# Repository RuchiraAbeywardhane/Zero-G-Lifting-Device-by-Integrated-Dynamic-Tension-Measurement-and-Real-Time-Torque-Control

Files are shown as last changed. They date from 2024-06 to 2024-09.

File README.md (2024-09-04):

# ZeroG Lifting Device by Integrated Dynamic Tension Measurement and Real Time Torque Control
Zero G Weight Support Device assists patients struggling with walking by providing weight support to practice and improve mobility. It combines advanced mechanical engineering and electronic control systems, offering a safe and effective rehabilitation tool. This device helps patients build strength and confidence in their walking abilities.

## Project Overview

The zero gravity lifting device is designed to counteract gravity, allowing objects to be lifted and manipulated with minimal effort. It uses a load cell to measure tension, processes this information through a PID controller, and adjusts a stepper motor's velocity to achieve the desired effect.

## Components

1. ATmega328P microcontroller
2. HX711 load cell amplifier
3. Stepper motor
4. Custom PCB

## Key Features

- Real-time weight measurement using HX711 load cell amplifier
- PID control algorithm for smooth and accurate motor control
- Stepper motor control for precise movements
- Millisecond time tracking for accurate derivative calculations

## Setup and Compilation

The project is developed using WinAVR for the ATmega328P microcontroller.

## Main Program Flow

1. Initialize USART, millisecond timer, and interrupts
2. Initialize and calibrate the HX711 load cell amplifier
3. Set up the PID controller
4. Enter the main loop:
   - Read weight from the load cell
   - Calculate weight change rate (derivative)
   - Process through PID controller
   - Control stepper motor based on PID output

## Notes for Developers

- The PID constants (P_FACTOR, I_FACTOR, D_FACTOR) may need tuning for optimal performance
- The DELAY_MICROSECONDS constant in the stepper motor control can be adjusted to change motor speed
- The HX711 calibration process is crucial for accurate weight measurements

## Code Details

### HX711 Library (`HX711.h`)

This custom library provides functions for interfacing with the HX711 load cell amplifier. Key functions include:

- `HX711_init()`: Initialize the HX711 module
- `HX711_read()`: Read raw data from the HX711
- `HX711_set_scale()`: Set the scale factor for weight conversion
- `HX711_tare()`: Set the tare weight
- `HX711_get_units()`: Get weight readings in desired units

### Millisecond Tracking Library (`millis.h`)

This lightweight library provides millisecond-level timing capabilities, which are crucial for calculating the rate of change in weight. Key functions include:

- `millis_init()`: Initialize the millisecond timer
- `millis_get()`: Get the current millisecond count
- `millis_reset()`: Reset the millisecond count to 0

### Main Program (`main.c`)

The main program integrates all components and implements the control logic. Key features include:

- PID controller implementation
- Stepper motor control
- Weight derivative calculation
- Debug output via USART

## Hardware Connections

- HX711 Data (DT) pin connected to PC4
- HX711 Clock (SCK) pin connected to PC3
- Stepper motor STEP pin connected to PD6
- Stepper motor DIR pin connected to PD7

## Calibration

The load cell requires calibration for accurate weight measurements. The current code uses a calibration factor of 222138.f, but this may need adjustment based on your specific load cell and setup.

## Tuning

For optimal performance, you may need to tune the following parameters:

1. PID constants (P_FACTOR, I_FACTOR, D_FACTOR)
2. DELAY_MICROSECONDS for stepper motor speed
3. SCALING_FACTOR for PID calculations

## Debugging

The code includes debug output via USART. You can monitor this output to see real-time information about:

- Weight derivative
- PID controller output

Use this information to help with tuning and troubleshooting.

## Future Improvements

Potential areas for future development include:

1. Implementing a user interface for easy control and monitoring
2. Adding limit switches or other safety features
3. Incorporating different lifting modes or profiles
4. Implementing wireless control or monitoring capabilities

## Contributing

Contributions to improve the code or extend the functionality are welcome. Please ensure you follow good coding practices and thoroughly test any changes.

## License

This project uses libraries with specific licenses:

- The millisecond tracking library is licensed under GNU GPL v3.
- Check the licensing terms for other components before use or distribution.

## Support

For questions or issues related to this project, please open an issue in the project repository or contact the project maintainers.

Remember to always prioritize safety when working with lifting devices and follow all relevant safety guidelines and regulations.

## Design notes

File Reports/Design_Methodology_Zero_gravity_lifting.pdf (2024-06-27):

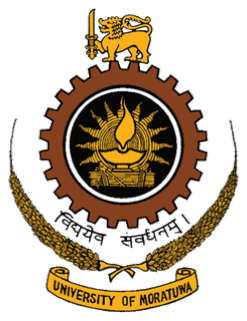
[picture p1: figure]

# Department of Electronic & Telecommunication Engineering

# University of Moratuwa

# Sri Lanka

# Design Methodology

# Zero gravity lifting device

Group Members:

210005H | Abeyrathna S M S M B
210015M | Abeywardhane R N
210321X | Kumarasinghe R D
210687X | Weerasinghe C N

30/04/2024

# 1 Review Progress

3

Zero Gravity Lifting | EN2160

## 1 Introduction

This report provides an overview of the progress made in the development of the Zero Gravity Arm/Lift Assist project, focusing on the application of innovative technologies to lift and manipulate materials in an industrial environment. The project aims to address challenges where traditional cranes or hoists may be impractical, offering a versatile solution with the Zero Gravity Part Manipulator Arm. Information presented here is derived from a comprehensive review of existing technologies, methodologies, and insights from reputable sources such as research articles, product documentation, and industry videos.

## 2 Review Progress

We conducted a thorough analysis of how various companies and universities are approaching the task of lifting and manipulating objects in zero gravity using a specialized lifter or arm. Our goal was to understand the current state of technology and gather insights into the methods and innovations being employed. We relied on sources such as YouTube videos, product brochures, and research articles to inform our understanding. This research serves as the foundation for our proposed project, helping us plan and design based on the latest advancements in zero-gravity lifting technology.

### 2.1 Zero Gravity Lifting Technologies: Manufacturer Innovations

In the review progress section, a dedicated subtopic focuses on exploring the cutting-edge zero gravity lifting technologies introduced by manufacturers. This subtopic delves into the unique features, advancements, and applications of zero-gravity lifting systems, with a specific emphasis on innovations brought forth by industry-leading manufacturers.

### 2.1.1 Gorbel Easy Arm Intelligent Lifting Arm: Ergonomic Partners

The Gorbel Easy Arm Articulating Smart Jib Cranes incorporate key technologies for efficient lifting.

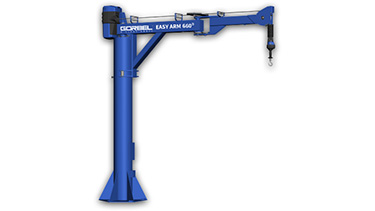
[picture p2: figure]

Figure 1: Gorbel Easy Arm Intelligent Lifting Arm

– G-Force Intelligent Hoist:

Integrates strength, precision, and speed with G-Force lifting technology.

– Flexible Installation:

Free-standing and under-hung options with various capacities and spans.

2

– Unmatched Precision:
Operates at speeds less than 1 fpm with two pivot points for delicate object handling.

– Handle Configurations:

Various handle options for user flexibility, including force-sensing handles.

– Cable Management:

G360 swivel assembly collector prevents cable tangling, ensuring smooth operation.

– Zero-Gravity Float Mode:
Allows precise load manipulation using hands, functioning as a true zero-gravity lifter.

∗ Webpage: https://www.ergonomicpartners.com/gorbel-g-force

∗ YouTube: Automotive Lift Assist with Zero Gravity Arm

- Link: https://www.youtube.com/watch?v=AF6rBc1sEww

### 2.1.2 Zero-Gravity suspended radiation protection system : Biotronik

The Zero-Gravity® Suspended Radiation Protection System addresses the increasing challenges faced by interventionists during fluoroscopic procedures. With a focus on reducing cumulative radiation doses and orthopedic strain, this innovative system eliminates the weight burden for operators, enhancing radiation protection without compromising mobility.

∗ Adaptable Configurations:

- Floor Unit: Repositionable for various procedures and easily stored.
- Monorail: Suspended from a ceiling-mounted rail, offering flexibility in room configurations and patient access.
- Hinged Swing Arm: Ideal when ceiling-mounted equipment restricts rail use, with single fixation point and stowable shield.
- Monorail Hinged Swing Arm: Combines advantages of Hinged Swing Arm and Monorail, providing maximum patient access.

After establishing contact with Biotronix, we successfully obtained their product brochure for the Zero-Gravity suspended radiation protection system. This valuable resource provided additional insights into the features, specifications, and applications of their innovative product, enhancing our understanding and contributing to the comprehensive analysis of radiation protection solutions in medical environments.

∗ Webpage: https://www.biotronik.com/en-sea/products/zero-gravity

### 2.1.3 Intelligent Devices for Handling INDEVA of the Liftronic Series fea-

turing advanced electronic control technology

The Liftronic INDEVA Intelligent Devices for Handling incorporate several advanced technologies to enhance their performance and user experience. Here are the key technologies used:

- Auto-weight sensing and auto-balancing capabilities

3

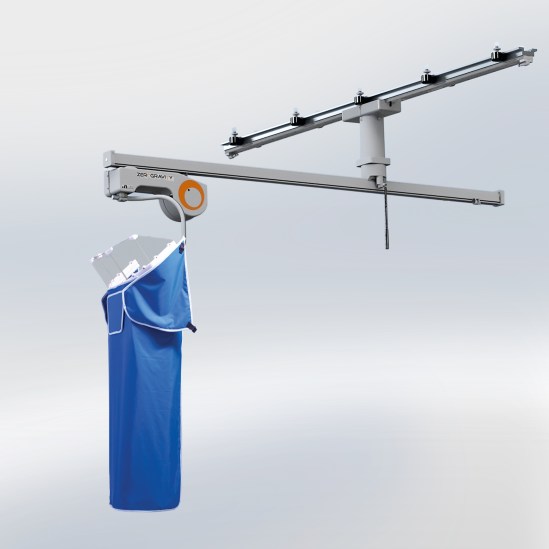
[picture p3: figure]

Figure 2: Zero-Gravity suspended radiation protection system

- Responsive and precise electronic control
- Ergonomic design for effortless handling
- Remote troubleshooting through App-Indeva
- Industry 4.0 interconnectivity
- Efficient auto diagnostic system
- Utilization of electronic control and automation
- Human extender technology for enhanced capabilities
- Tailored for speed, fluid movement, and precise load positioning

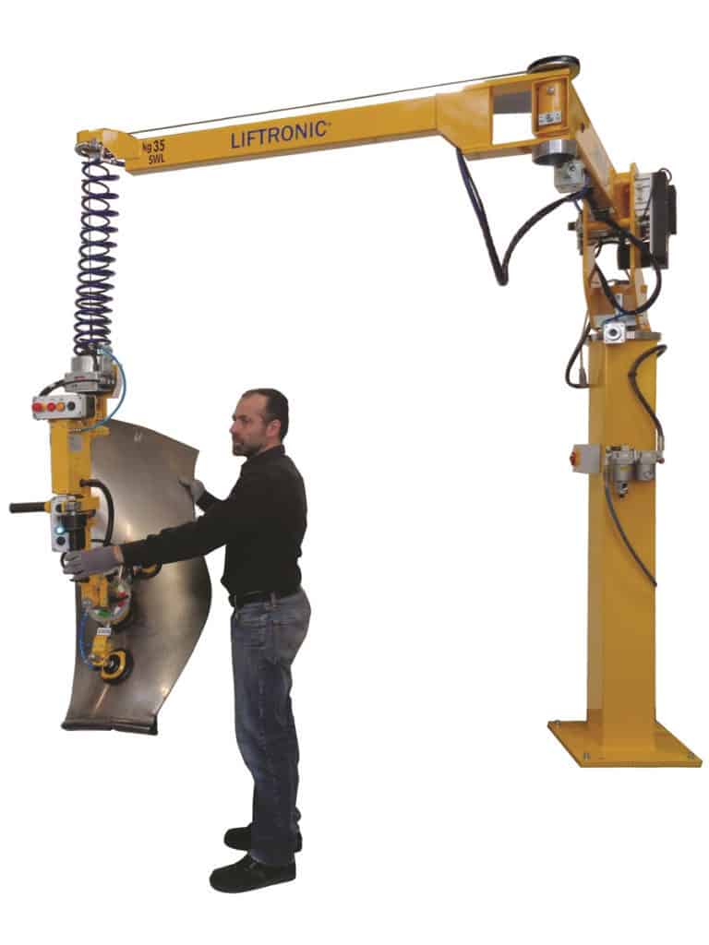
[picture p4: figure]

Figure 3: The Liftronic

∗ Webpage: https://www.indevagroup.com/industrial-manipulators/

4

∗ Video: https://youtu.be/GRpa-XghiB4

### 2.2 Evaluating Servo Motor Pros and Cons

Our investigation within the realm of zero gravity lifting technologies included a focused examination of the advantages and disadvantages associated with the available servo motors. This analysis aims to provide a comprehensive understanding of the positive attributes and limitations of servo motors, facilitating informed decision-making in their application within zero gravity lifting systemsIn the review progress section, a dedicated subtopic focuses on exploring the cutting-edge zero gravity lifting technologies introduced by manufacturers. This subtopic delves into the unique features, advancements, and applications of zero-gravity lifting systems, with a specific emphasis on innovations brought forth by industry-leading manufacturers.

## 3 Plan next steps

Having laid the foundation with an insightful exploration into existing technologies and methodologies for zero gravity lifting, our next steps involve a strategic plan to delve deeper into the intricacies of this cutting-edge field. We are currently studying available servo motors, assessing their pros and cons.

1. Technology Research:

Conduct in-depth research on existing zero gravity lifting technologies, considering advancements, industry standards, and manufacturer specifications.

2. Identification of Optimal Technologies:

Define criteria for evaluating zero gravity lifting technologies, focusing on factors such as efficiency, precision, adaptability, and safety.

3. Prototype Development:

Initiate the development of a prototype based on the chosen zero gravity lifting model, incorporating the fine-tuned algorithms and mechanisms necessary for operation in a weightless environment.

4. Testing and Validation:

Conduct rigorous testing and validation procedures to ensure the reliability and performance of the zero gravity lifting system under various conditions.

5. Safety Protocols Implementation:

Prioritize the integration of safety protocols and fail-safe mechanisms to guarantee secure and efficient operation in zero gravity environments.

6. Documentation and Reporting:

Document the entire process, including model selection, fine-tuning, and integration steps, providing a comprehensive report for future reference and continuous improvement.

5

## 4 Stakeholder analysis

Understanding the interests and influence levels of these stakeholders is crucial for effective project management and successful implementation of zero gravity lifting technologies.

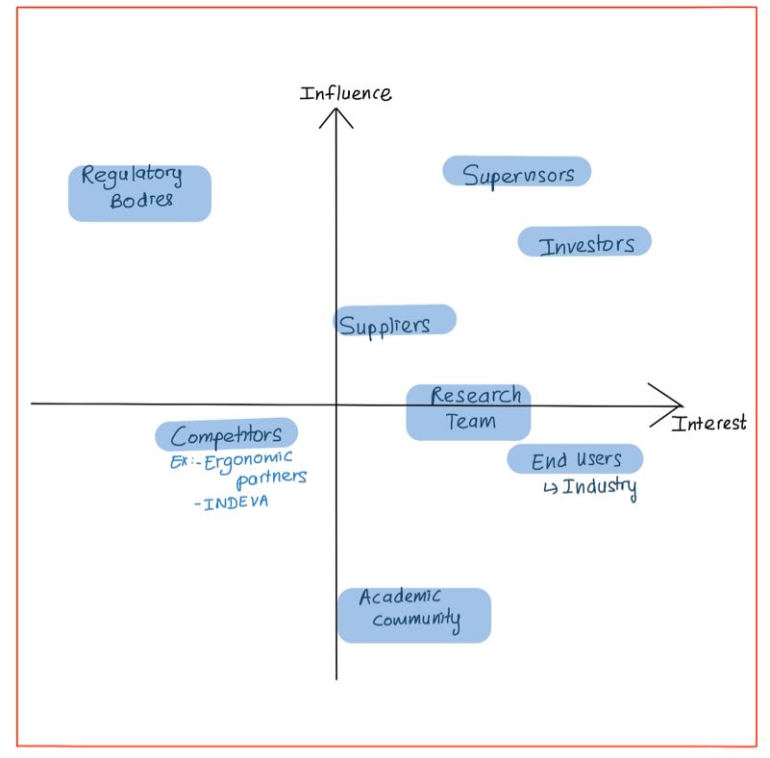
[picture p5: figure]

Figure 4: Stakeholder Map

## 5 Conclusion

In conclusion, our exploration into zero gravity lifting technologies has been methodical and insightful. We’ve delved into advanced solutions, established criteria for evaluation, and initiated the development of a prototype. The stakeholder analysis underlines the importance of collaboration for project success. As we move forward, integrating safety measures and documenting each step is key to building a strong foundation. The focus on a prototype represents a practical step toward realizing a functional zero gravity lifting system. Our decision-making process prioritizes efficiency, adaptability, and precision. This journey is not just about technology; it’s a step into a future where zero gravity

6

lifting can transform from idea to reality, revolutionizing industrial applications. Moving forward, our commitment to innovation, safety, and collaboration will drive us towards unprecedented advancements in zero gravity lifting.

7

# 2 Conceptual Design

5

## 1 Introduction

This design of prototype report presents three innovative approaches for the enclosure of the Zero Gravity Arm/Lift Assist project and 3 conceptual designs for sensor technology and conceptual designs emphasizing their potential applications in lifting and manipulating materials within industrial settings.

These designs primarily focus on controlling the servo motor smoothly and sensing input data to enable precise lifting and tension maintenance of the cable according to the weight being lifted. Smooth control of the servo motor ensures precise movement and positioning of the lifting device, enhancing its efficiency and accuracy in industrial lifting operations. Additionally, incorporating sensors to detect input data such as weight allows for real-time adjustments in lifting operations, ensuring safe and reliable handling of materials within industrial settings. Given the critical role of these electronic components in the overall functionality of the lifting device, it is imperative to explore innovative conceptual designs that optimize control and sensing capabilities.

Furthermore, three conceptual designs are introduced for each aspect of the electronic components—servo motor control and sensor technology. This approach allows for thorough exploration of alternative solutions and ensures that a comprehensive range of possibilities is considered during the evaluation process. By presenting multiple conceptual designs, the project aims to identify the most effective and efficient solutions that address the specific requirements and challenges of the Zero Gravity Arm/Lift Assist project, ultimately contributing to its successful implementation in industrial settings.

The primary objective is to explore alternative solutions where conventional cranes or hoists may pose limitations. The next section outlines the evaluation process that scrutinizes the three conceptual designs, ultimately selecting the most optimal solution for implementation. The final section includes the enclosure design and schematic and PCB of the selected conceptual design.

## 2 User Requirements

- Purpose: The purpose of the Box Lifting Device is to provide users with a safe and user-friendly solution for lifting and manipulating heavy objects.
- Functional Requirements:

– Payload Compatibility: The device must be capable of lifting various payload sizes and shapes within specified weight limits to accommodate diverse lifting tasks.

- Safety Requirements:

– Overload Protection: The device should include mechanisms to detect and prevent overloading, ensuring safe operation and preventing damage to the device and payloads.

– Emergency Stop: Include an emergency stop feature to immediately halt device operation in case of emergencies or unexpected situations, prioritizing user safety.

- Ease of Use Requirements:

– Intuitive Controls: Design the control interface with intuitive controls and clear labeling to enable easy operation by users with minimal training or experience.

– Ergonomic Design: Ensure the device is ergonomically designed with comfortable handles and grips, reducing user fatigue and enhancing user comfort during prolonged use.

– Clear Feedback: Provide clear visual or auditory feedback to users to indicate the device’s status and any relevant alerts or warnings during operation.

2

– Quick Setup: Facilitate quick and straightforward setup procedures for the device, including assembly, calibration, and configuration, to minimize downtime and enable users to start using the device promptly.

## 3 Mechanical conceptual designs

### 3.1 Design 1

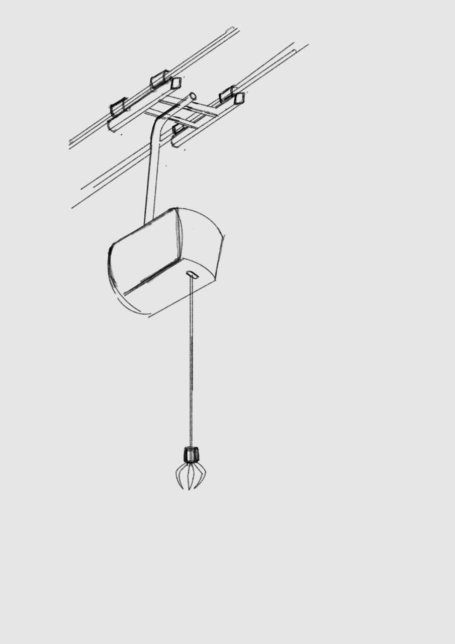
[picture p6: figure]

Figure 1: Design 1

The first conceptual design for a zero gravity lifting device tailored for industrial applications centers on a box housing a servo motor, facilitating movement along a robust steel bar track. Complementing this setup is a claw mechanism chosen as the primary grabbing tool. The design’s degree of freedom is characterized by its ability to move along the axis.

3

### 3.2 Design 2

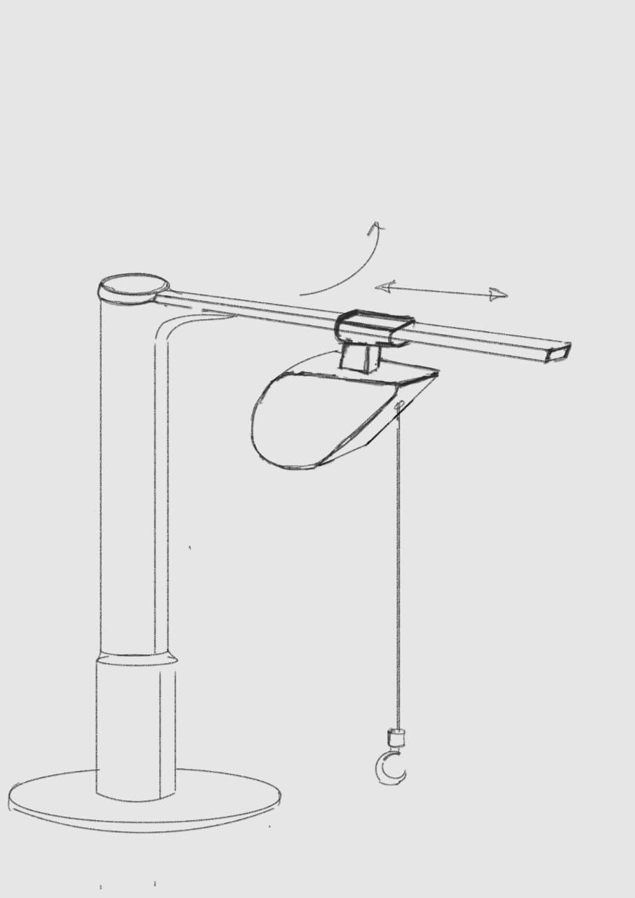
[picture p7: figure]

Figure 2: Design 2

For the second conceptual design of a zero gravity lifting device, we introduce a hook mechanism as the primary grabbing tool. This design incorporates a two-degree-of-freedom system, allowing the hook to rotate around a central column for approximately 270 degrees while also traversing along a horizontal bar track. This configuration offers enhanced flexibility and maneuverability, enabling the device to efficiently handle a wide range of lifting tasks within industrial environments. By combining the rotational capability of the hook with its horizontal movement along the bar track, this design provides increased versatility in accessing and lifting objects of varying shapes and sizes, thereby optimizing operational efficiency in industrial settings.

4

### 3.3 Design 3

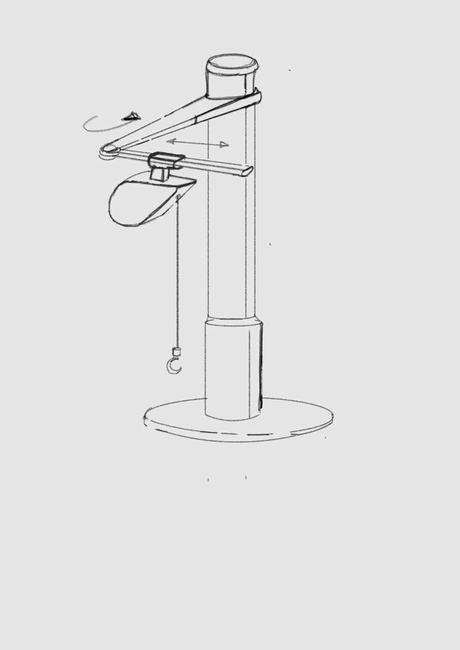
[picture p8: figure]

Figure 3: Design 3

In the third conceptual design iteration, we introduce a lifting device with a third degree of freedom to further enhance its capabilities for industrial applications. This additional degree of freedom adds complexity to the implementation process due to the need for intricate mechanisms and control systems.
The third degree of freedom in this design allows for vertical movement in addition to the horizontal traversal along the steel bar track and the rotational capability of the grabbing mechanism. This vertical movement enables the device to adjust its lifting position, accommodating varying heights of objects within the industrial environment.

5

### 3.4 Evaluation Criteria

To evaluate and select the optimal conceptual design for the zero gravity lifting device, we propose the following evaluation criteria:

- Maneuverability and Flexibility: Assess the degree to which each design facilitates movement in multiple directions within the industrial environment. Evaluate how effectively each design can navigate obstacles and reach various workstations or assembly points.
- Complexity and Implementation: Assess the complexity of implementing each design, considering factors such as manufacturing feasibility, assembly requirements, and maintenance considerations. Evaluate the potential challenges and resources required for constructing and deploying each design in real-world industrial settings.
- Operational Efficiency: Assess the overall efficiency and productivity gains offered by each design in performing lifting tasks within industrial environments. Consider factors such as speed of operation, ease of use, and compatibility with existing workflows or systems.
- Cost Effectiveness: Evaluate the cost-effectiveness of each design, considering factors such as initial investment, maintenance costs, and potential savings or productivity gains achieved through improved lifting capabilities and operational efficiency.
- Versatility and Adaptability: Assess the versatility and adaptability of each design in accommodating diverse lifting requirements and handling various types of objects commonly encountered in industrial settings. Consider the design’s ability to accommodate future modifications or upgrades to meet evolving operational needs.

By thoroughly evaluating each conceptual design against these criteria, we can determine the optimal solution that best aligns with the requirements and priorities of industrial lifting applications.

### 3.5 Evaluation and Comparison of conceptual Designs

| Conceptual design 1 | Conceptual design 2 | Conceptual design 3
Maneuverability and Flexibility | 5 | 8 | 9
Complexity and Implementation | 8 | 8 | 5
Operational Efficiency | 6 | 8 | 8
Cost-effectiveness | 7 | 9 | 7
Versatility and Adaptability | 7 | 8 | 7
Total | 33 | 41 | 36

Table 1: Evaluation and Comparison of mechanical conceptual Designs

### 3.5.1 Selected Design- Design 2

Among the three conceptual designs evaluated based on maneuverability and flexibility, conceptual design 2 received the highest score of 8. This design showcased superior maneuverability and flexibility, attributed to its two-degree-of-freedom system allowing rotation around a column while moving along a horizontal bar track. This capability enhances the device’s adaptability to navigate around obstacles and reach various workstations or assembly points within industrial environments.

6

Additionally, the rotational feature of the grabbing mechanism enables efficient handling of objects positioned at different angles, contributing to enhanced flexibility in lifting operations. Furthermore, conceptual design 2 excelled in operational efficiency with a score of 8, reflecting its ability to optimize productivity in industrial lifting tasks. The integration of a two-degree-offreedom system provides precise control over lifting operations, enabling the device to efficiently handle a wide range of object weights and sizes commonly encountered in industrial applications. Additionally, the design’s versatility and adaptability contribute to its operational efficiency by accommodating diverse lifting requirements and seamlessly integrating with existing workflows or systems. As a result, conceptual design 2 emerges as the optimal choice, offering a balanced combination of maneuverability, efficiency, and versatility to meet the diverse needs of industrial lifting applications.

## 4 Design for controlling servo motor

Controlling servo motors effectively is crucial for the successful operation of the Zero Gravity Arm/Lift Assist project. Servo motors play a pivotal role in providing precise and controlled movement to the lifting device, allowing it to navigate through industrial environments with accuracy and efficiency. The ability to control servo motors smoothly directly impacts the device’s maneuverability, positioning, and overall performance. Smooth control ensures that the lifting device can precisely lift, lower, and manipulate materials without causing damage to the surroundings or compromising safety.
This control process provides adjustable limit and gain control, enabling a more responsive and efficient movement of the load. At the core of this process is the utilization of user input to command the desired force, facilitated through a switch mechanism. The force command is then compared with the actual force measured by a force sensor, generating a force error signal indicative of any deviation. Subsequently, the dynamic limit module dynamically adjusts the output of the gain amplifier based on predetermined limit values, preventing abrupt changes in force command and ensuring stability during lifting operations. Furthermore, by dynamically limiting the velocity vector command output according to the weight of the load, the control process optimizes maneuverability, particularly for heavier loads where higher inertia necessitates careful handling. Ultimately, this approach aims to provide precise control over the servo motor, enhancing the overall efficiency and safety of the lifting device in industrial environments.

7

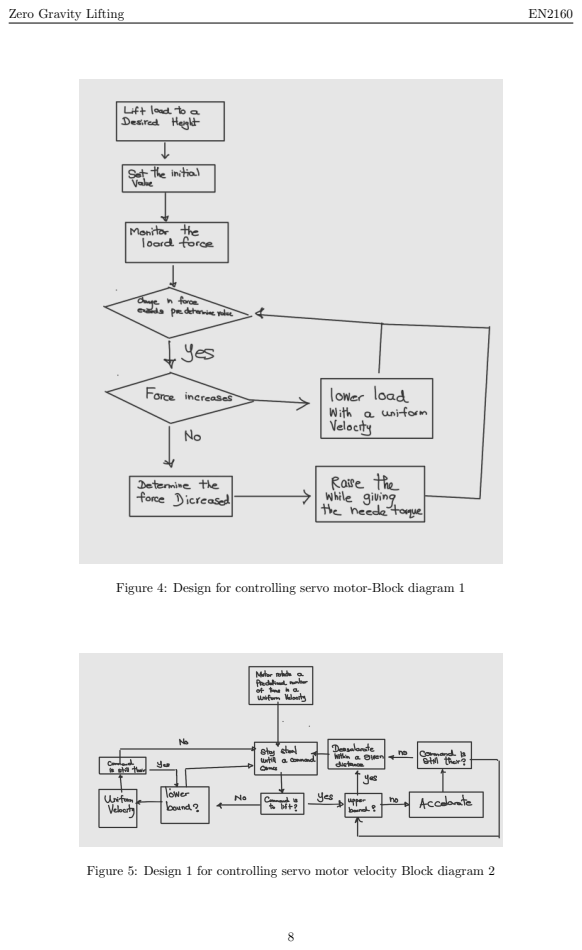
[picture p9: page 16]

Figure 4: Design for controlling servo motor-Block diagram 1

Figure 5: Design 1 for controlling servo motor velocity Block diagram 2

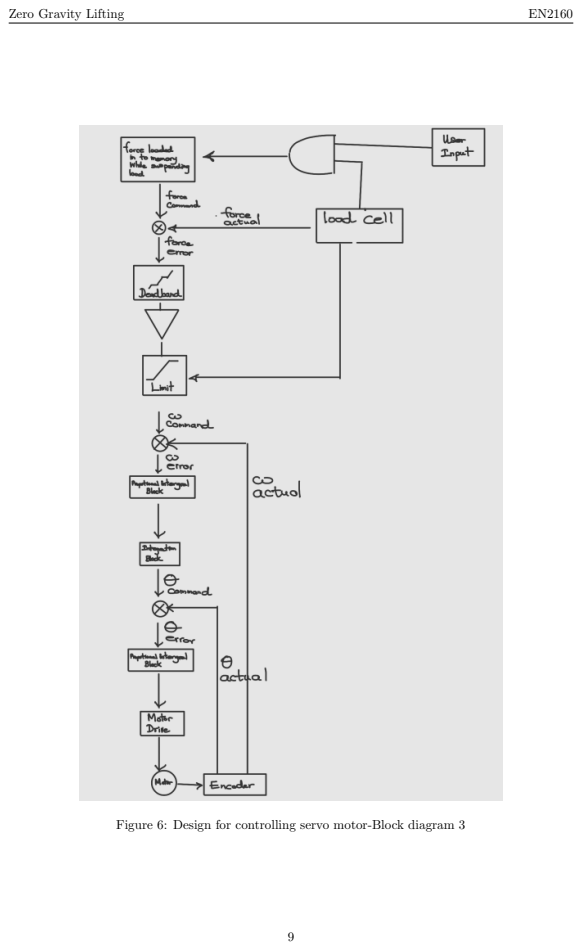
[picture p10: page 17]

Figure 6: Design for controlling servo motor-Block diagram 3

## 5 Conceptual Designs for signal input

### 5.1 Design 1

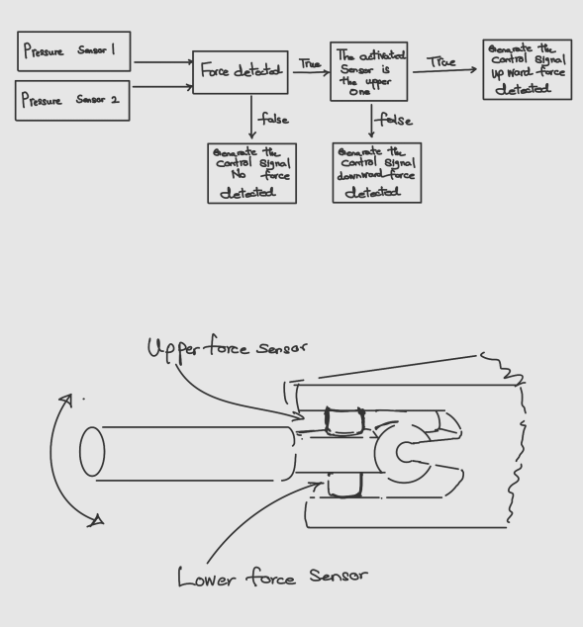
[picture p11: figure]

Figure 7: Design 1

This concept uses two pressure sensors at the users handle therefore has better sensitivity and ease of use. Since pressure sensors output an analog signal, we can design the system to have a varying velocity proportional to the force enforced on the box by the user giving a more realistic zero gravity feeling to the user. We can use more cost-effective pressure sensors since the range is at the lower side. Consequently, the load cells/pressure sensors won’t have to deal with large forces therefore the design will be simpler. And more importantly the range of the load cell does not depend on the weight of the box, which will make the design more effective and simpler.

10

### 5.2 Design 2

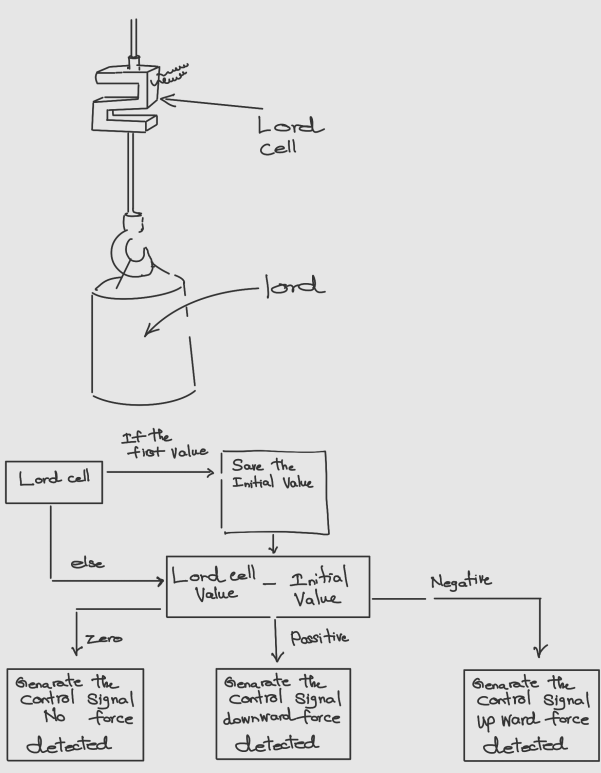
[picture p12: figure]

Figure 8: Design 2

This concept uses a load cell in between the cable and the box to be lifted. We will have to use more sophisticated load cells with a wider range and the range will depend on the weight of the box. Which will consequently make the design complex and arise difficulties in finding the optimal load cell. Since the load cells also output an analog signal, we can design the system to have a varying velocity proportional to the force enforced on the box by the user giving a more realistic zero gravity feeling to the user.

11

### 5.3 Design 3

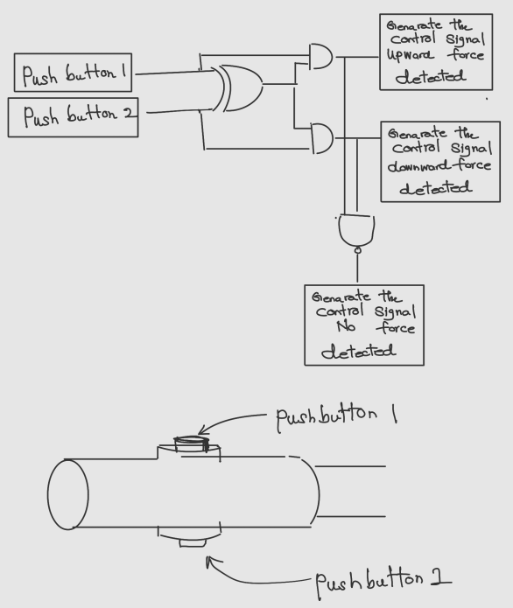
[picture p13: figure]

Figure 9: Design 2

This concept uses two push buttons at the users handle/ Since push buttons output a digital signal, we cannot design the system to have a varying velocity. Therefore, the realistic zero gravity feeling will be lost in this design. Rather it will give a machinery feeling to the user. This design will also be cost effective since the push buttons are not very expensive.

12

### 5.4 Evaluation Criteria

To evaluate and select the optimal conceptual design for the zero gravity lifting device, we propose the following evaluation criteria:

- Sensing Sensitivity: Evaluate the ability of the sensing mechanism to accurately detect subtle changes in force applied to the lifting device. Higher sensitivity allows for finer control and smoother operation, enhancing user experience and efficiency in lifting tasks.
- Realism of Feedback: Assess the extent to which the sensing mechanism can replicate the sensation of zero gravity or weightlessness, providing users with a realistic perception of the lifting process. Realistic feedback enhances user engagement and immersion in the task, contributing to improved performance and satisfaction.
- Compatibility with System Complexity: Consider the compatibility of the sensing mechanism with the overall complexity of the lifting device design. Evaluate whether the chosen sensing technology can be seamlessly integrated into the system architecture without significantly increasing complexity or compromising performance.
- Cost-Effectiveness: Analyze the cost-effectiveness of the sensing solution, taking into account factors such as sensor price, maintenance requirements, and long-term reliability. A cost-effective sensing mechanism offers value for money while meeting performance requirements.
- Ease of Implementation: Assess the ease of implementation and deployment of the sensing mechanism within the lifting device design. Consider factors such as sensor installation, calibration procedures, and compatibility with existing hardware and software components.
- Weight Dependency: Analyze how the sensing mechanism adjusts its response according to variations in the weight of the lifted object. Evaluate whether the sensing technology can effectively handle objects of different weights while maintaining sensitivity and realism in feedback.

### 5.5 Evaluation and Comparison of conceptual Designs

This criterion assesses the effectiveness of the sensing mechanism in providing accurate and realistic feedback to the user during lifting operations. It considers the sensitivity of the sensing system in detecting force variations and its ability to translate these variations into realistic motion responses.

| Conceptual design 1/Pressure sensors | Conceptual design/Push Button 2 | Conceptual design 3/Load cell
Sensing Sensitivity | 8 | 8 | 6
Realism of Feedback | 8 | 6 | 6
Compatibility with System Complexity | 9 | 8 | 6
Cost-effectiveness | 8 | 9 | 7
Ease of Implementation | 8 | 8 | 7
Dependency on weight | 9 | 9 | 5
Total | 50 | 48 | 37

Table 2: Evaluation and Comparison of sensing mechanism conceptual Designs

13

### 5.5.1 Selected Design-Design 1

Based on the evaluation and comparison of the three conceptual designs for sensing mechanisms, Conceptual Design 1 utilizing pressure sensors emerges as the most optimal choice for the Zero Gravity Arm/Lift Assist project. This design scored highest in Sensing Sensitivity and Realism of Feedback, indicating superior performance in accurately detecting force variations and providing realistic feedback to the user during lifting operations. Additionally, it achieved commendable scores in Compatibility with System Complexity, Cost-effectiveness, and Ease of Implementation, showcasing its suitability for seamless integration into the overall system architecture while offering value for money and ease of deployment. By incorporating pressure sensors at the user’s handle, this design ensures better sensitivity, ease of use, and a more realistic zero gravity feeling for the user, enhancing overall user experience and operational efficiency. Therefore, Conceptual Design 1 stands out as the optimal choice, promising enhanced performance, realism, and user satisfaction in zero gravity lifting operations within industrial settings.

14

## 6 Enclosure Design of the prototype

The enclosure design of the prototype for the Zero Gravity Arm/Lift Assist project is pivotal in ensuring the functionality, safety, and durability of the device within industrial settings. Crafted from high-strength materials such as reinforced plastics or metals, the enclosure provides robust protection to internal components against environmental elements such as dust, moisture, and mechanical stresses. To enhance structural integrity, beams within the enclosure, suitable for a height of 2 meters, are typically fabricated from materials like aluminum or steel, chosen for their strengthto-weight ratio and resistance to deformation under load.

A meticulous approach is taken in the design process, where numerous part files are created for individual components before assembly using software like SolidWorks. This ensures precise fitment and compatibility among parts, contributing to the overall reliability of the enclosure. Additionally, SolidWorks is utilized to create the enclosure, ensuring accurate modeling and integration of all components.

15

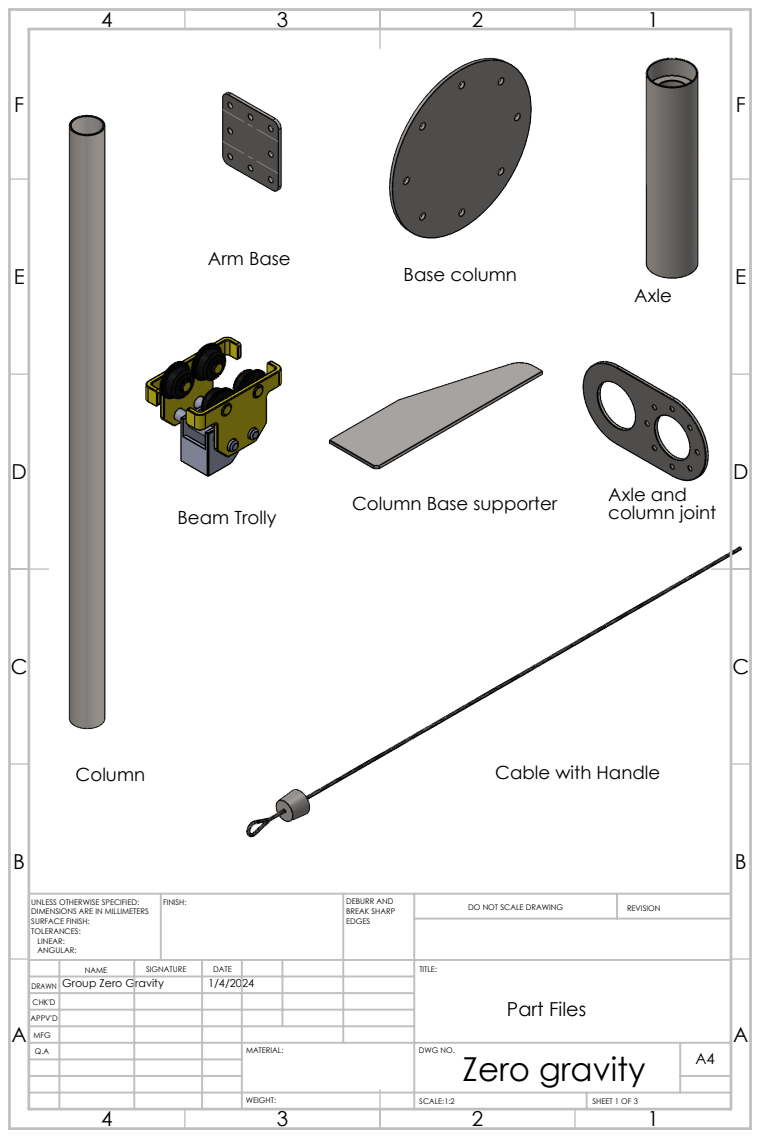
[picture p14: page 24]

UNLESS OTHERWISE SPECIFIED:
DIMENSIONS ARE IN MILLIMETERS
SURFACE FINISH:
TOLERANCES:
LINEAR:
ANGULAR:

NAME | SIGNATURE | DATE | | | TITLE: Part Files

DRAWN | Group Zero Gravity | | 1/4/2024

CHK'D
APPV'D
MFG
Q.A | | | | MATERIAL: | DWG NO. Zero gravity | A4

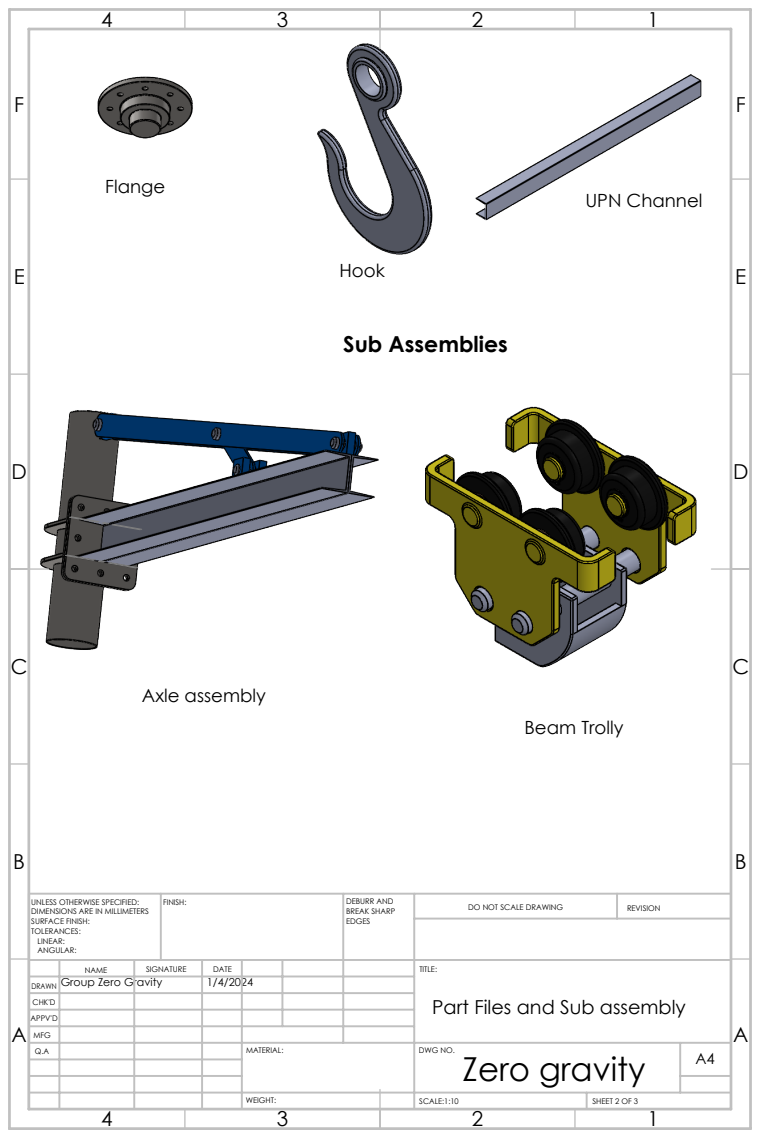
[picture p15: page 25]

UNLESS OTHERWISE SPECIFIED:
DIMENSIONS ARE IN MILLIMETERS
SURFACE FINISH:
TOLERANCES:
LINEAR:
ANGULAR:

DRAWN | Group Zero Gravity | | 1/4/2024

NAME | SIGNATURE | DATE | | | TITLE: Part Files and Sub assembly

CHK'D
APPV'D
MFG
Q.A | | | | MATERIAL: | DWG NO. Zero gravity | A4

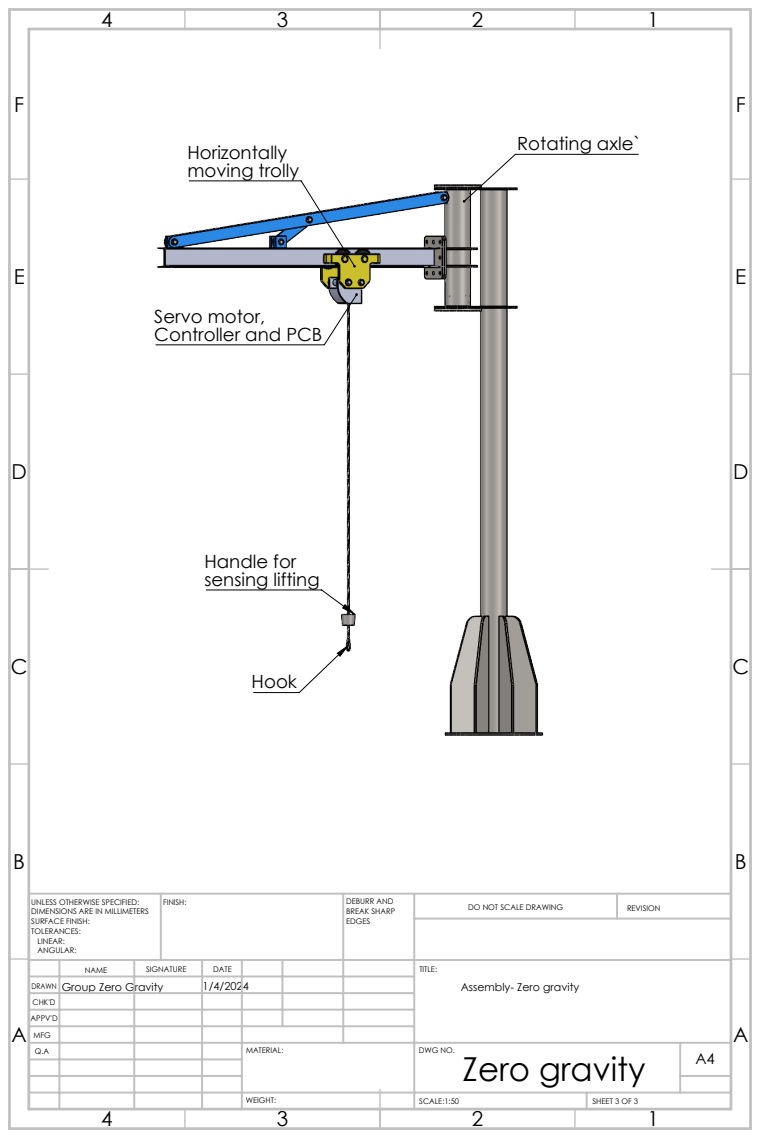
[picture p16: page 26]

UNLESS OTHERWISE SPECIFIED:
DIMENSIONS ARE IN MILLIMETERS
SURFACE FINISH:
TOLERANCES:
LINEAR:
ANGULAR:

NAME | SIGNATURE | DATE | | | TITLE: Assembly- Zero gravity
DRAWN | Group Zero Gravity | | 1/4/2024
CHK'D
APPV'D
MFG
Q.A | | | | MATERIAL: | DWG NO. Zero gravity | A4

## 7 Schematic and PCB design of the prototype

The Box Lifting Device utilizes an Atemega328P chip as its microcontroller. To power up the stepper motor, a 12V AC to DC adapter is used, which is then stepped down to 5V using a buck converter to supply the necessary voltage to the Atmega chip. Additionally, two pressure sensors are integrated with the microcontroller to detect user actions such as lifting and releasing the box. Based on these inputs and other relevant parameters, appropriate control signals are generated and sent to the TB6600 stepper motor controller for regulating the NEMA23 stepper motor.

19

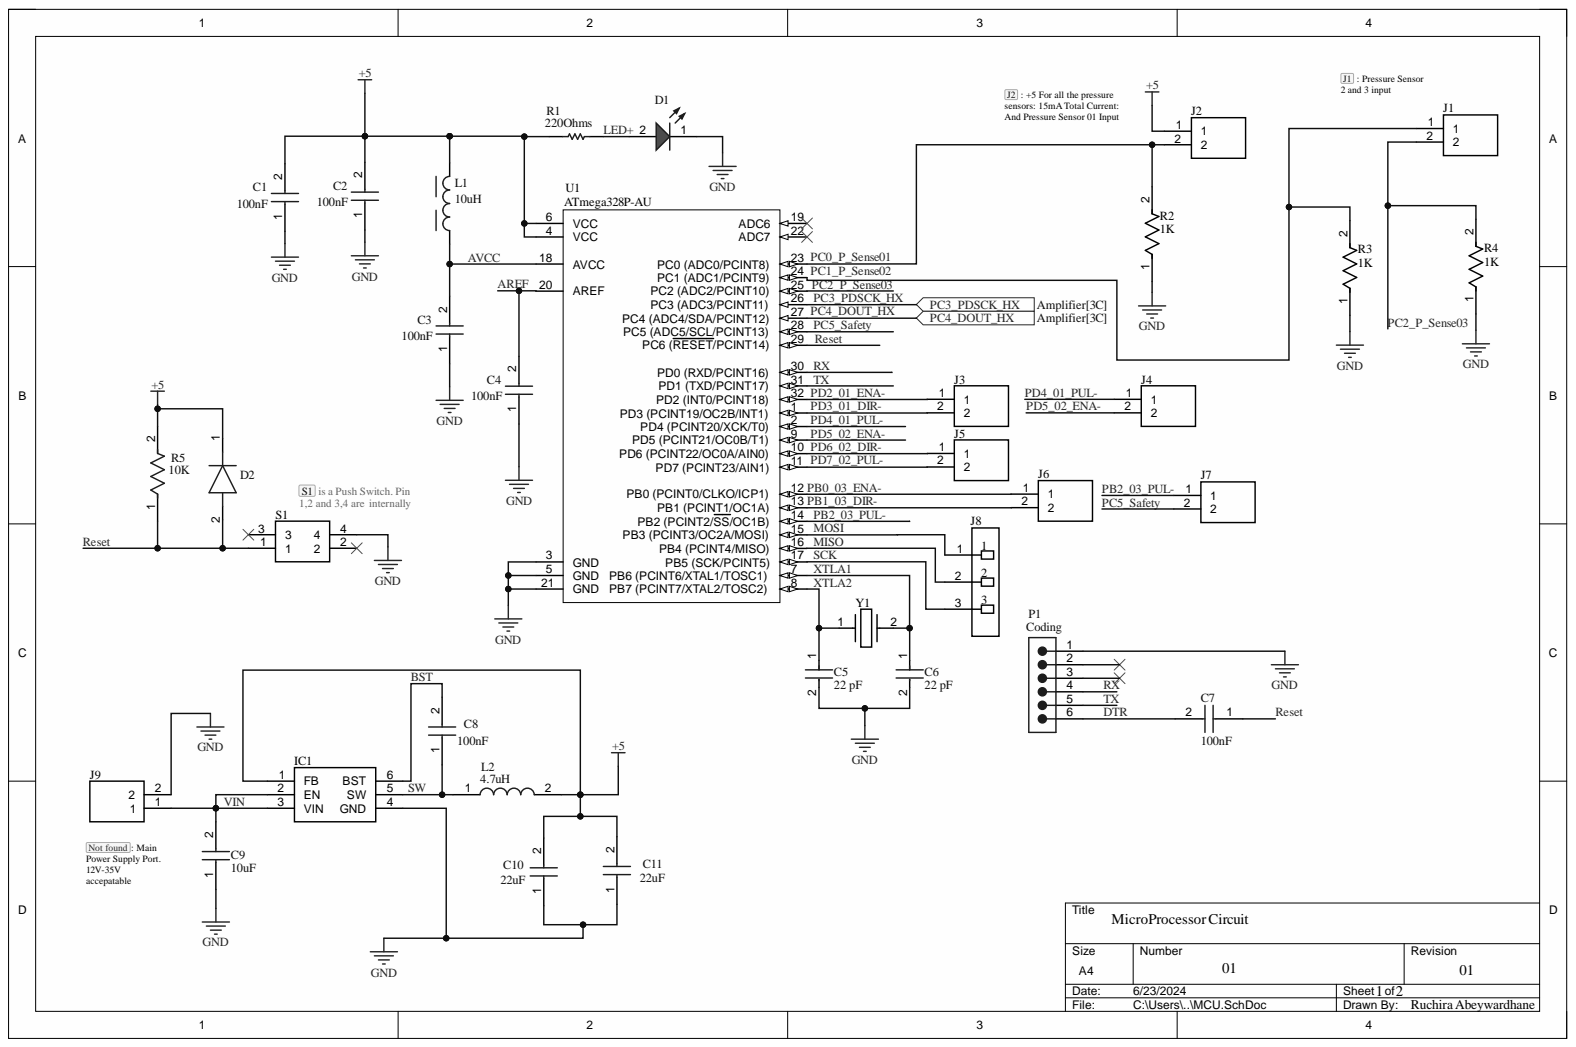
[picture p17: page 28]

5 | 7 | XTL A 1 | 123 | 123

8 | XTL A 2

S i z e A 4 | Number 0 1 | Rev i s i o n 0 1

Date: 6/23/2024 | Sheet of 1 2
F i le: C:\User s\..\MCU.S chDoc | Drawn B y : Ruchir a Abeywardhane

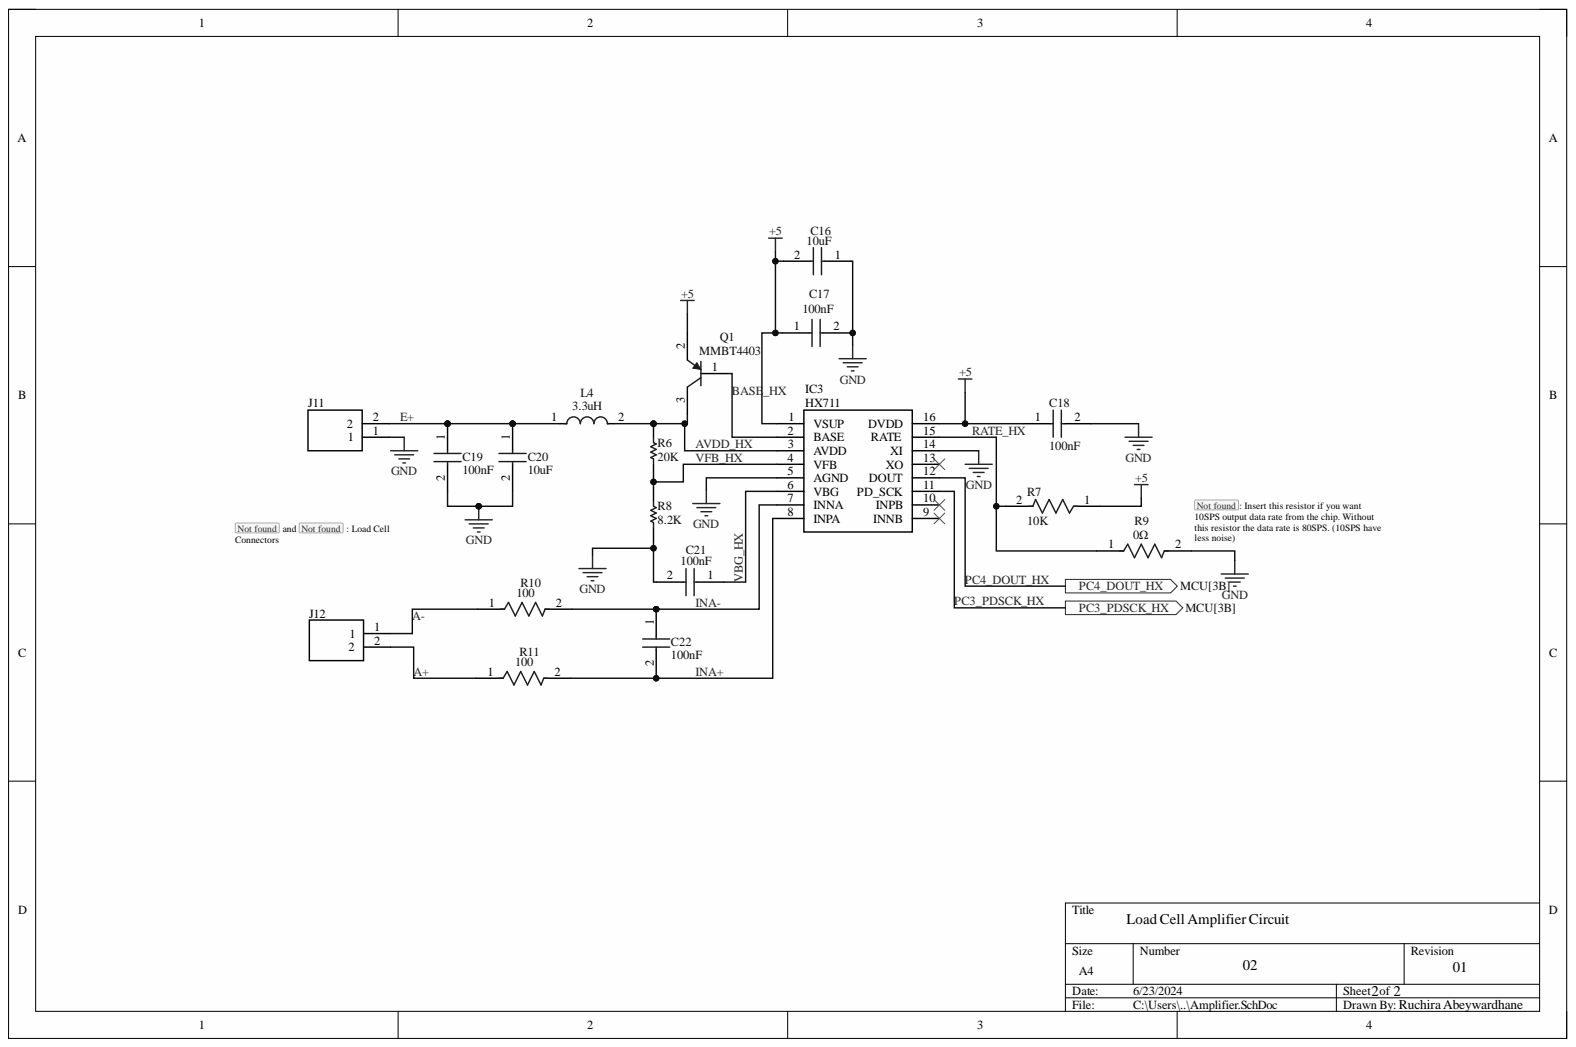
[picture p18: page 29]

10SPS output data rate from the chip. Without
this resistor the data rate is 80SPS. (10SPS have

Not found and Not found : Load Cell
Connectors

Size A4 | Number 02 | Revision 01

Date: 6/23/2024 | Sheet of 2 2
File: C:\Users\..\Amplifier.SchDoc | Drawn By: Ruchira Abeywardhane

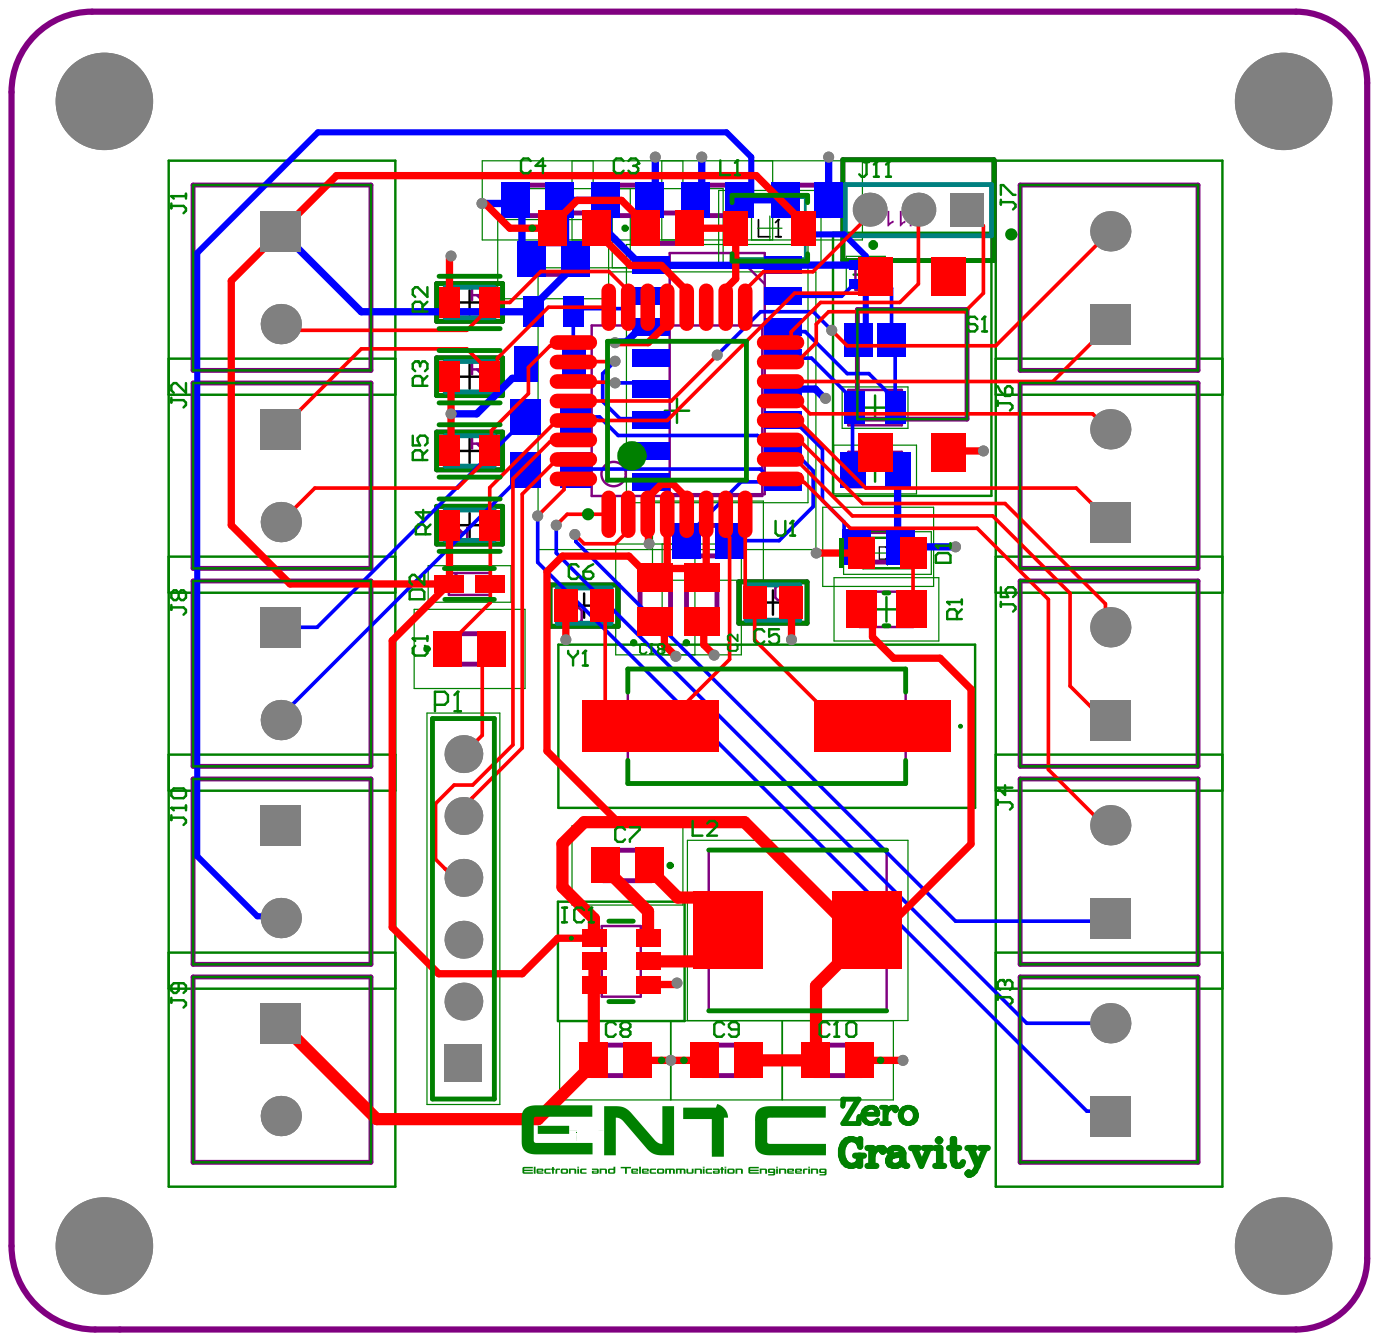
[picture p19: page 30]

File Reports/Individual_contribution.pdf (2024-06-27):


# Department of Electronic & Telecommunication Engineering

# University of Moratuwa

# Sri Lanka

# Individual Contribution to the Zero Gravity Group Project

210015M Abeywardhane R N

23/06/2024

Zero Gravity Lifting | EN2160

## Background Search Contribution

I conducted a preliminary exploration of available components, such as servo motors and motor drivers, and verified their availability through reliable component providers as advised by Professor Jayasinghe during our first meeting. This research helped in identifying suitable design models for our project, achieving the first learning outcome.

## Documentation Contribution

I created detailed design documentation for the electronic parts, including the reasoning behind each selection. This thorough documentation process ensured that our design choices were well-founded and clearly communicated, fulfilling the fifth learning outcome.

## PCB Contribution

I designed the schematic and PCB layout using Altium Designer, ensuring the design was testable and complied with industry standards. This task met the second learning outcome by producing a PCB that adhered to professional standards.

## SolidWorks Contribution

I inspected and validated the enclosure using SolidWorks to ensure it fit perfectly with the selected components. This process ensured that the product enclosure met industry standards, fulfilling the fourth learning outcome.

## Soldering Contribution

I soldered the SMD components, ensuring proper assembly and functionality. This hands-on work demonstrated my understanding of electronic manufacturing processes, meeting the third learning outcome.

## Code Contribution

I inspected the code and tested it with the circuits to identify and resolve any bugs. This debugging process ensured the software worked seamlessly with the hardware, contributing to the creation of a working prototype and fulfilling the sixth learning outcome.

## Summary

Through my contributions to component research, design documentation, schematic and PCB layout design, enclosure validation, soldering, and code inspection, I effectively supported the project’s goals and achieved the key learning outcomes necessary for my development as an engineer.

1

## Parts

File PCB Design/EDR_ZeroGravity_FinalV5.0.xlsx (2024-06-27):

Comment | Description | Designator | Quantity
C0805Y104J3RACTU | Capacitor | C1, C2, C3, C4, C7, C11, C12, C14, C15, C16 | 20
C0805C220F1HACTU | C0805 22 pF X8R 30ppm/°C 1.00% 100 V | C5, C6 | 5
C0805C106K4PAC7210 | Capacitor 10uF | C8, C13, C17 | 6
C0805C226K9PACTU | Capacitor 22uF | C9, C10 | 5
150080RS75000 | LED | D1 | 5
CDSU4148 | Diode | D2 | 3
AP63205WU-7 | Integrated Circuit _ Buck Converter | IC1 | 3
744764910 | Inductor 10uH, 10%, 1 Element, SMD, 1210 | L1 | 3
SRP7028CC-4R7M | Inductor 4.7uH | L2 | 3
MLZ2012A3R3WTD25 | Shielded Multilayer Inductor 3.3uH ±20% 450mA 442mΩ AEC-Q200 SMD 0805 | L3 | 3
TSW-106-07-L-S | 0.025" SQ Post Header, Through-hole, Vertical, -55 to 125 degC, 2.54 mm Pitch, 6-Pin, Male, RoHS | P1 | 1
MMBT4403M3T5G | PNP Switching Transistor, 3-Pin SOT-723, Pb-Free, Tape and Reel | Q1 | 3
RK73H2ATTD2200F | 220Ohms | R1 | 5
RK73H2ATTD1001D | 1kΩ ±0.5% 0.25W Chip Resistor 0805 Thick Film AEC-Q200 Qualified | R2, R3, R5 | 6
RK73H2ATTED1002F | 10kΩ ±1% 0.25W Chip Resistor 0805 Thick Film AEC-Q200 Qualified | R4, R7 | 5
RK73H2ATTD2002F | 20K | R6 | 5
RK73H2ATTD8201F | 8.2K | R8 | 5
RK73H2ATTED1000F | 100Ω ±1% 0.25W Chip Resistor 0805 Thick Film AEC-Q200 Qualified | R9, R10 | 5
RCC08050000Z0EA | RCC08050000Z0EA Res Thick Film 0805 0 Ohm Conformal Coated Pad SMD Automotive AEC-Q200 T/R | R11 | 10
TL3305BF160QG | Switch | S1 | 2
ATmega328P-AU | 8-bit AVR Microcontroller, 32KB Flash, 1KB EEPROM, 2KB SRAM, 32-pin TQFP, Industrial Grade (-40°C to 85°C) | U1 | 3
ECS-160-18-5PX-GM-TR | Crystal or Oscillator | Y1 | 3

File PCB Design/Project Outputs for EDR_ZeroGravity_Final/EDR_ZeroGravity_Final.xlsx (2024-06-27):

Comment | Description | Designator | Footprint | LibRef | Quantity
C0805Y104J3RACTU | Capacitor | C1, C2, C3, C4, C7 | C0805 | C0805Y104J3RACTU | 5
C0805C220F1HACTU | C0805 22 pF X8R 30ppm/°C 1.00% 100 V | C5, C6 | FP-C0805C-DN-MFG | CMP-03020-009085-1 | 2
C0805C106K4PAC7210 | Capacitor | C8 | C0805 | C0805C106K4PAC7210 | 1
C0805C226K9PACTU | Capacitor | C9, C10 | C0805 | C0805C226K9PACTU | 2
CDSU4148 | Diode | D1 | DIOM179X85N | CDSU4148 | 1
AP63205WU-7 | Integrated Circuit | IC1 | AP63205WU7 | AP63205WU-7 | 1
440054-2 | CONN HEADER VERT 2POS 2MM | J1, J2, J5 | FP-440054-2-MFG | CMP-03369-000005-1 | 3
B6B-XH-A(LF)(SN) | Connector Header Through Hole 6 position 0.098 (2.50mm) | J3, J4 | JST_B6B-XH-A(LF)(SN) | B6B-XH-A(LF)(SN) | 2
694106106102 |  | J6 | 694106106102 | CMP-1502-00177-3 | 1
744764910 | 744764910 General Purpose Inductor, 10uH, 10%, 1 Element, SMD, 1210 | L1 | WE-GFH_3225 | CMP-03913-61645378-1 | 1
SRP5030CC-4R7M | Inductor | L2 | INDPM5752X300N | SRP5030CC-4R7M | 1
RK73H2ATTD1001D | 1kΩ ±0.5% 0.25W Chip Resistor 0805 Thick Film AEC-Q200 Qualified | R1, R2 | FP-RK73H2A-IPC_C | CMP-04015-089471-1 | 2
RK73H2ATTED1002F | 10kΩ ±1% 0.25W Chip Resistor 0805 Thick Film AEC-Q200 Qualified | R3 | FP-RK73H2A-IPC_C | CMP-04015-088604-1 | 1
TL3305BF160QG | Switch | S1 | TL3305BF160QG | TL3305BF160QG | 1
ATmega328P-AU | 8-bit AVR Microcontroller, 32KB Flash, 1KB EEPROM, 2KB SRAM, 32-pin TQFP, Industrial Grade (-40°C to 85°C) | U1 | 32A_M | CMP-0095-00269-2 | 1
830034122 | Crystal or Oscillator | Y1 | 830034122 | 830034122 | 1

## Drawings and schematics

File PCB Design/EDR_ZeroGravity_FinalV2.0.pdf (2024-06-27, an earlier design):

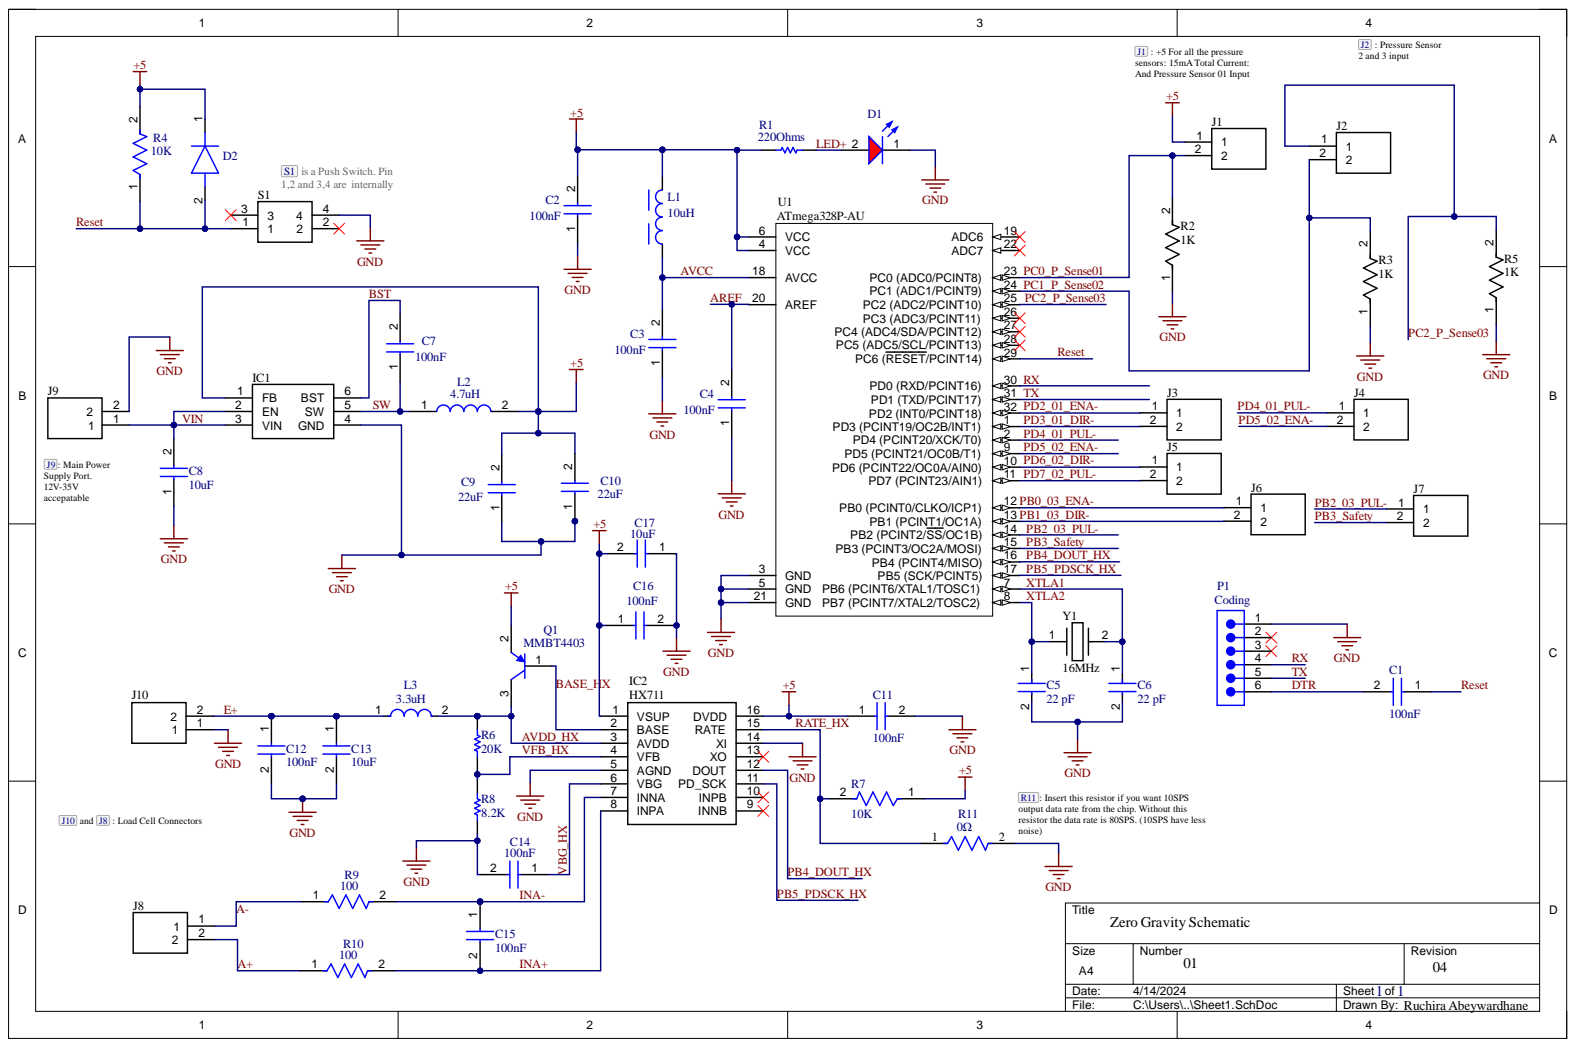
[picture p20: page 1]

J1 : +5 For all the pressure
sensors: 15mA Total Current:
And Pressure Sensor 01 Input

S1 is a Push Switch. Pin
1,2 and 3,4 are internally

R11 : Insert this resistor if you want 10SPS
output data rate from the chip. Without this
resistor the data rate is 80SPS. (10SPS have less
noise)

J10 and J8 : Load Cell Connectors

Size A4 | Number 01 | Revision 04

Date: 4/14/2024 | Sheet of 1 1
File: C:\Users\..\Sheet1.SchDoc | Drawn By: Ruchira Abeywardhane

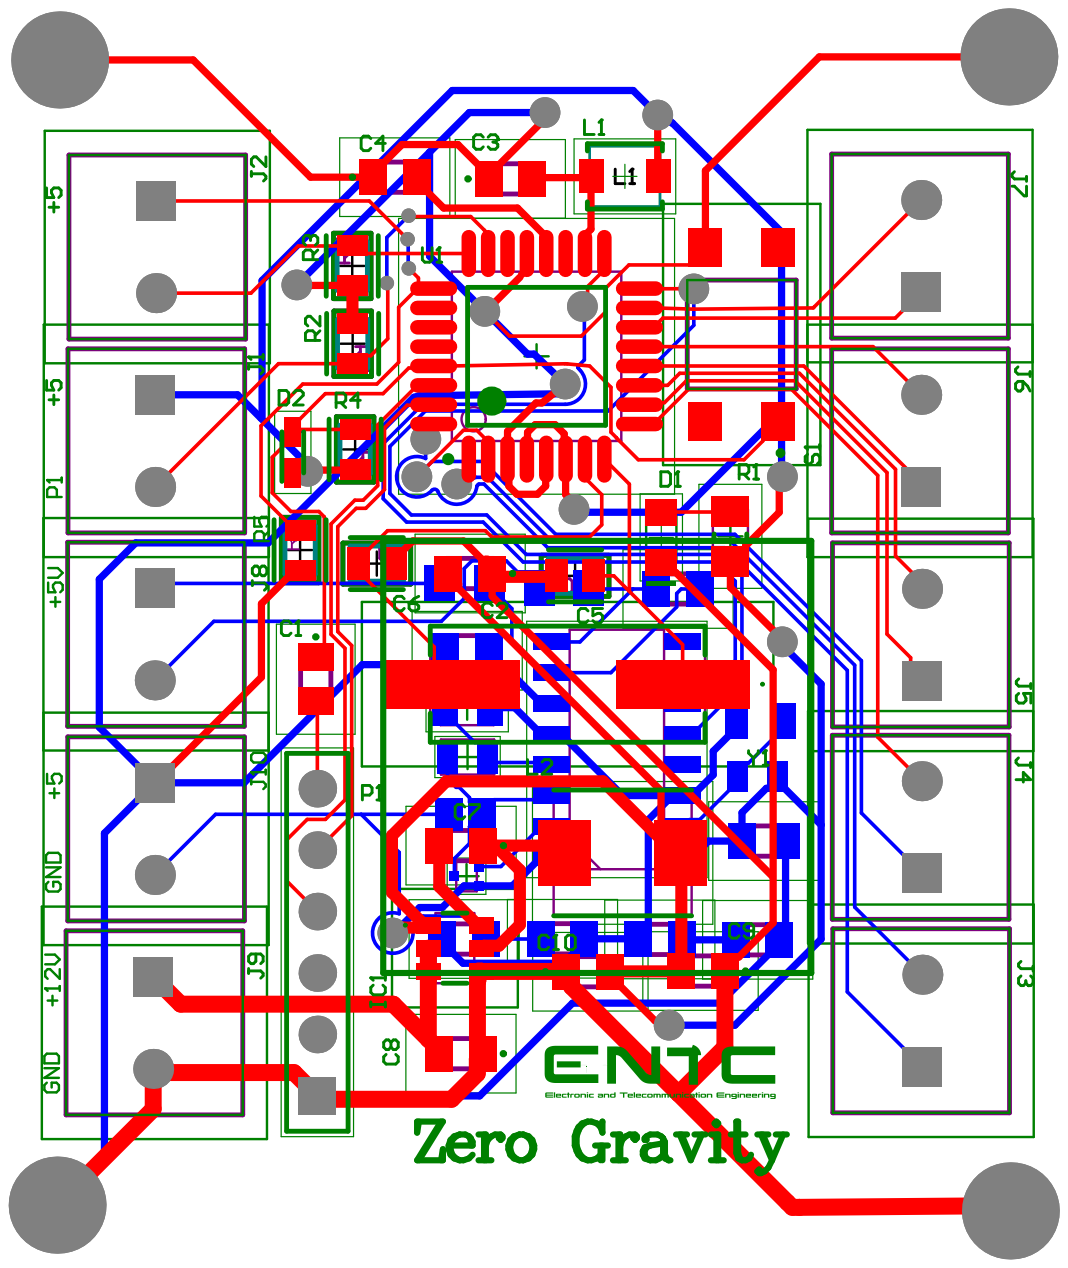
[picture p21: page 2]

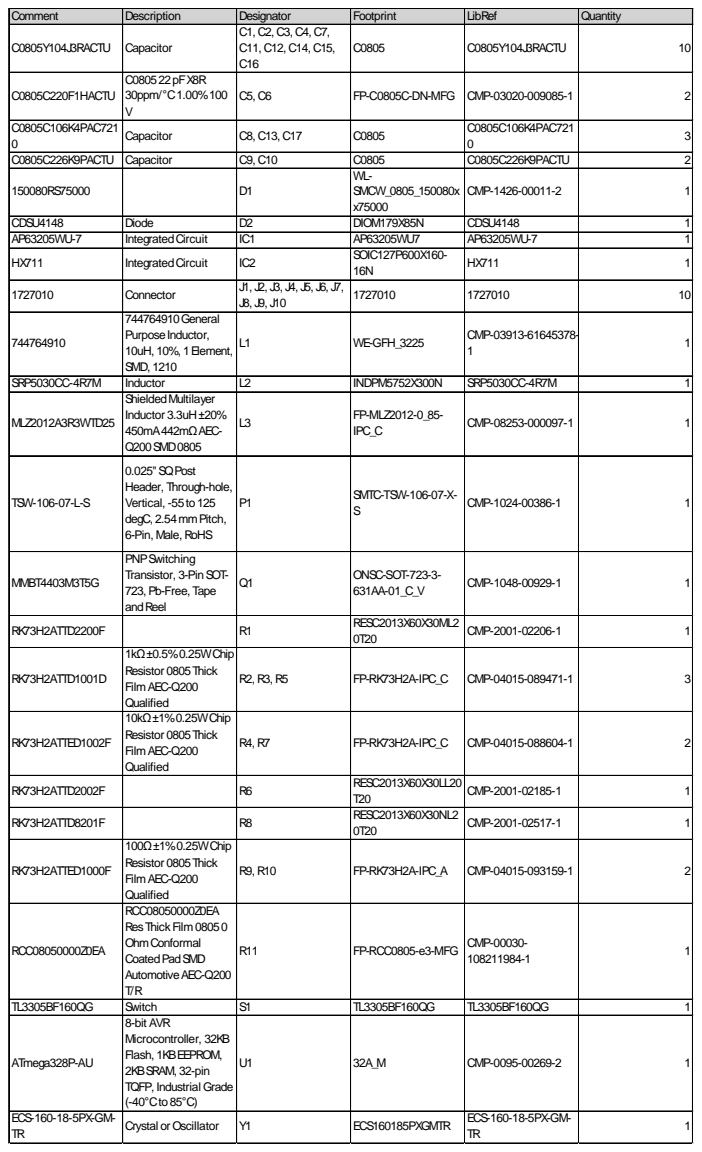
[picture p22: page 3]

Comment | Description | Designator | Footprint | LibRef | Quantity
C0805Y104J3RACTU | Capacitor | C1, C2, C3, C4, C7, C11, C12, C14, C15, C16 | C0805 | C0805Y104J3RACTU | 10

C0805C220F1HACTU | C080522pFX8R 30ppm/°C1.00%100 V | C5, C6 | FP-C0805C-DN-MFG | CMP-03020-009085-1 | 2

C0805C106K4PAC721 0 | Capacitor | C8, C13, C17 | C0805 | C0805C106K4PAC721 0 | 3

C0805C226K9PACTU | Capacitor | C9, C10 | C0805 | C0805C226K9PACTU | 2
150080RS75000 | | D1 | WL-SMCW_0805_150080x x75000 | CMP-1426-00011-2 | 1

CDSU4148 | Diode | D2 | DIOM179X85N | CDSU4148 | 1
AP63205WU-7 | IntegratedCircuit | IC1 | AP63205WU7 | AP63205WU-7 | 1
HX711 | IntegratedCircuit | IC2 | SOIC127P600X160-16N | HX711 | 1

1727010 | Connector | J1, J2, J3, J4, J5, J6, J7, J8, J9, J10 | 1727010 | 1727010 | 10

744764910 | 744764910General PurposeInductor, 10uH, 10%, 1Element, SMD, 1210 | L1 | WE-GFH_3225 | CMP-03913-61645378-1 | 1

SRP5030CC-4R7M | Inductor | L2 | INDPM5752X300N | SRP5030CC-4R7M | 1
MLZ2012A3R3WTD25 | ShieldedMultilayer Inductor 3.3uH±20% 450mA442mΩAEC-Q200SMD0805 | L3 | FP-MLZ2012-0_85-IPC_C | CMP-08253-000097-1 | 1

TSW-106-07-L-S | 0.025"SQPost Header, Through-hole, Vertical, -55to125 degC, 2.54mmPitch, 6-Pin, Male, RoHS | P1 | SMTC-TSW-106-07-X-S | CMP-1024-00386-1 | 1

MMBT4403M3T5G | PNPSwitching Transistor, 3-PinSOT-723, Pb-Free, Tape andReel | Q1 | ONSC-SOT-723-3-631AA-01_C_V | CMP-1048-00929-1 | 1

RK73H2ATTD2200F | | R1 | RESC2013X60X30ML2 0T20 | CMP-2001-02206-1 | 1

RK73H2ATTD1001D | 1kΩ±0.5%0.25WChip Resistor 0805Thick Film AEC-Q200 Qualified | R2, R3, R5 | FP-RK73H2A-IPC_C | CMP-04015-089471-1 | 3

RK73H2ATTED1002F | 10kΩ±1%0.25WChip Resistor 0805Thick Film AEC-Q200 Qualified | R4, R7 | FP-RK73H2A-IPC_C | CMP-04015-088604-1 | 2

RK73H2ATTD2002F | | R6 | RESC2013X60X30LL20 T20 | CMP-2001-02185-1 | 1

RK73H2ATTD8201F | | R8 | RESC2013X60X30NL2 0T20 | CMP-2001-02517-1 | 1

RK73H2ATTED1000F | 100Ω±1%0.25WChip Resistor 0805Thick Film AEC-Q200 Qualified | R9, R10 | FP-RK73H2A-IPC_A | CMP-04015-093159-1 | 2

RCC08050000Z0EA | RCC08050000Z0EA ResThickFilm 08050 OhmConformal CoatedPadSMD AutomotiveAEC-Q200 T/R | R11 | FP-RCC0805-e3-MFG | CMP-00030-108211984-1 | 1

TL3305BF160QG | Switch | S1 | TL3305BF160QG | TL3305BF160QG | 1
ATmega328P-AU | 8-bit AVR Microcontroller, 32KB Flash, 1KBEEPROM, 2KBSRAM, 32-pin TQFP, Industrial Grade (-40°Cto85°C) | U1 | 32A_M | CMP-0095-00269-2 | 1

ECS-160-18-5PX-GM-TR | Crystal or Oscillator | Y1 | ECS160185PXGMTR | ECS-160-18-5PX-GM-TR | 1

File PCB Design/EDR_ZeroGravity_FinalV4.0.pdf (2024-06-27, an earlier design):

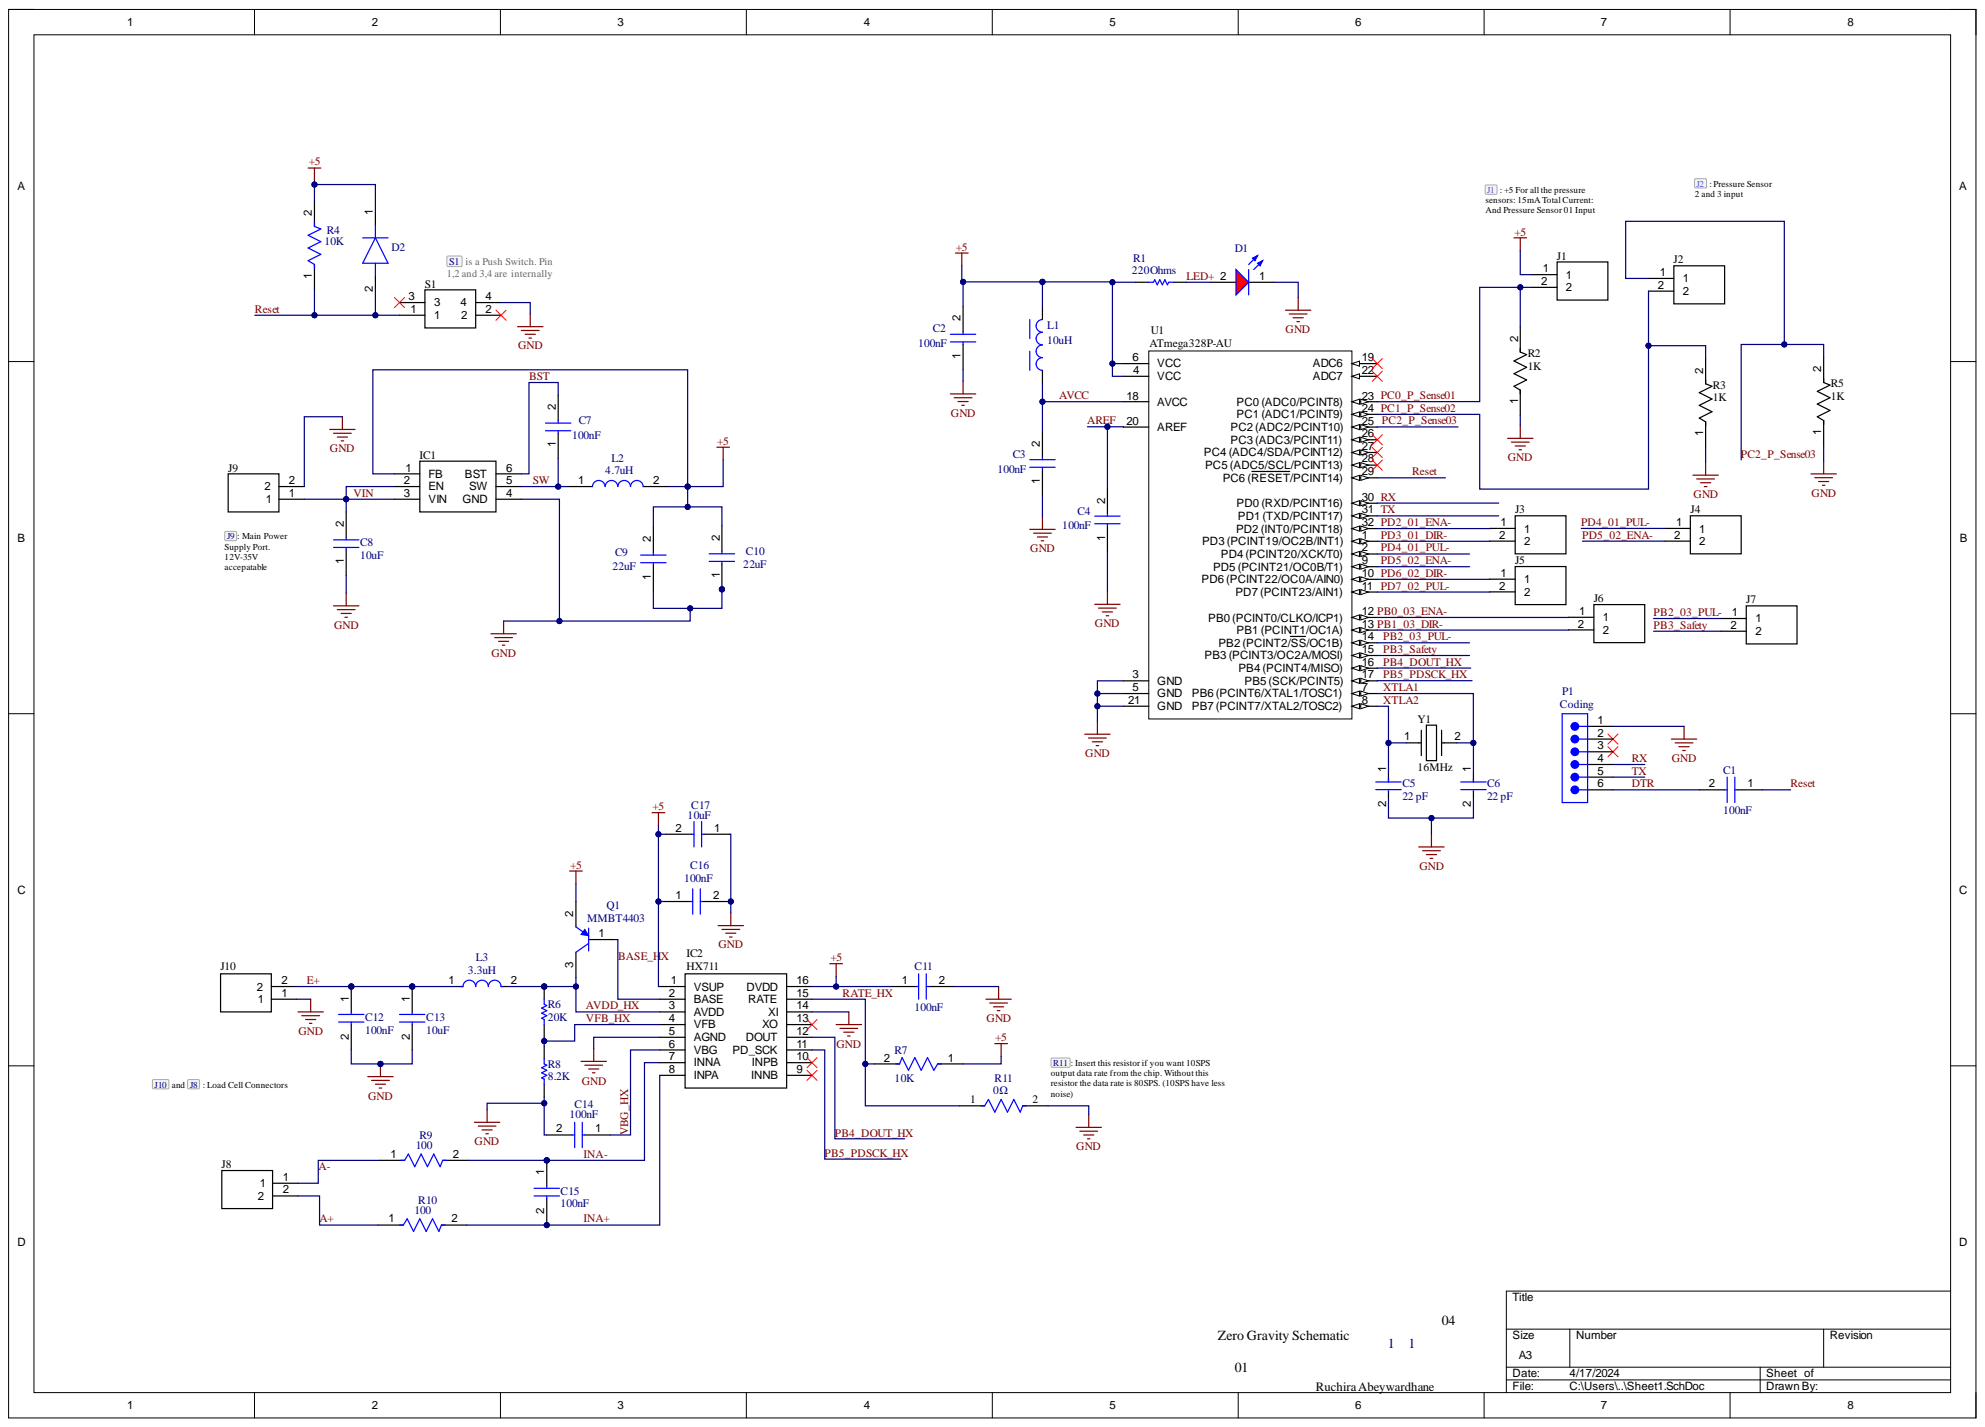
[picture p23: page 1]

J1 : +5 For all the pressure
sensors: 15mA Total Current:
And Pressure Sensor 01 Input

S1 is a Push Switch. Pin
1,2 and 3,4 are internally

VIN

R11 : Insert this resistor if you want 10SPS
output data rate from the chip. Without this
resistor the data rate is 80SPS. (10SPS have less
noise)

J10 and J8 : Load Cell Connectors

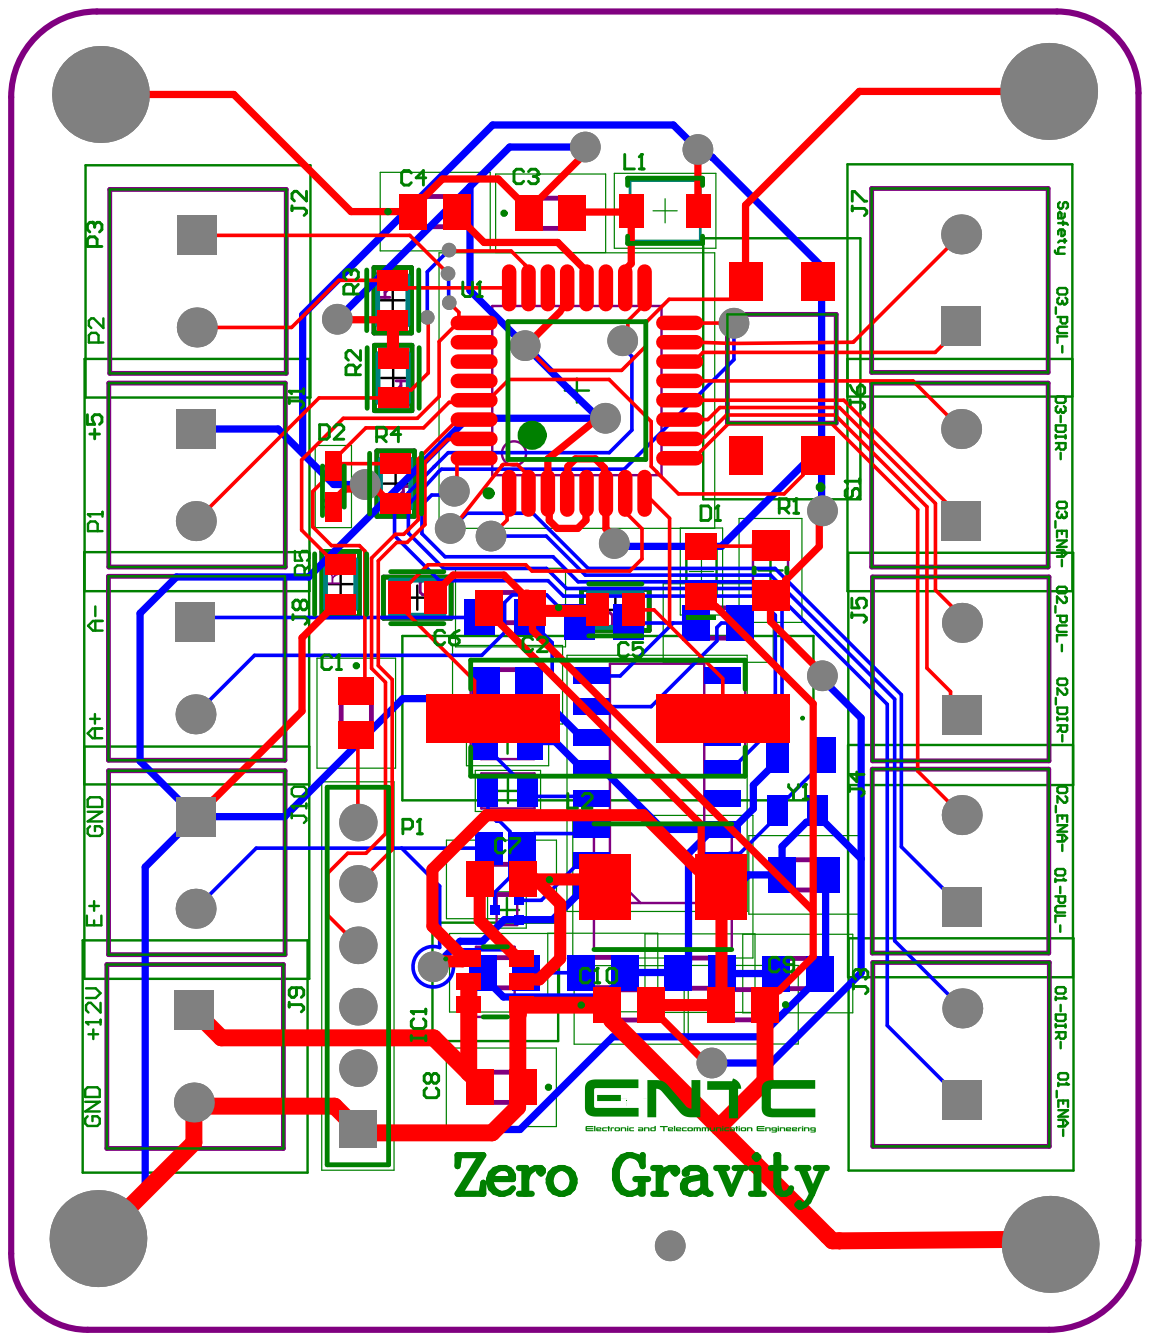
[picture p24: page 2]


Comment | Description | Designator | Footprint | LibRef | Quantity
C0805Y104J3RACTU | Capacitor | C1, C2, C3, C4, C7, C11, C12, C14, C15, C16 | C0805 | C0805Y104J3RACTU | 10

C0805C220F1HACTU | C080522pFX8R 30ppm/°C1.00%100 V | C5, C6 | FP-C0805C-DN-MFG | CMP-03020-009085-1 | 2

C0805C106K4PAC721 0 | Capacitor | C8, C13, C17 | C0805 | C0805C106K4PAC721 0 | 3

C0805C226K9PACTU | Capacitor | C9, C10 | C0805 | C0805C226K9PACTU | 2
150080RS75000 | | D1 | WL-SMCW_0805_150080x x75000 | CMP-1426-00011-2 | 1

CDSU4148 | Diode | D2 | DIOM179X85N | CDSU4148 | 1
AP63205WU-7 | IntegratedCircuit | IC1 | AP63205WU7 | AP63205WU-7 | 1
HX711 | IntegratedCircuit | IC2 | SOIC127P600X160-16N | HX711 | 1

1727010 | Connector | J1, J2, J3, J4, J5, J6, J7, J8, J9, J10 | 1727010 | 1727010 | 10

744764910 | 744764910General PurposeInductor, 10uH, 10%, 1Element, SMD, 1210 | L1 | WE-GFH_3225 | CMP-03913-61645378-1 | 1

SRP5030CC-4R7M | Inductor | L2 | INDPM5752X300N | SRP5030CC-4R7M | 1
MLZ2012A3R3WTD25 | ShieldedMultilayer Inductor 3.3uH±20% 450mA442mΩAEC-Q200SMD0805 | L3 | FP-MLZ2012-0_85-IPC_C | CMP-08253-000097-1 | 1

TSW-106-07-L-S | 0.025"SQPost Header, Through-hole, Vertical, -55to125 degC, 2.54mmPitch, 6-Pin, Male, RoHS | P1 | SMTC-TSW-106-07-X-S | CMP-1024-00386-1 | 1

MMBT4403M3T5G | PNPSwitching Transistor, 3-PinSOT-723, Pb-Free, Tape andReel | Q1 | ONSC-SOT-723-3-631AA-01_C_V | CMP-1048-00929-1 | 1

RK73H2ATTD2200F | | R1 | RESC2013X60X30ML2 0T20 | CMP-2001-02206-1 | 1

RK73H2ATTD1001D | 1kΩ±0.5%0.25WChip Resistor 0805Thick Film AEC-Q200 Qualified | R2, R3, R5 | FP-RK73H2A-IPC_C | CMP-04015-089471-1 | 3

RK73H2ATTED1002F | 10kΩ±1%0.25WChip Resistor 0805Thick Film AEC-Q200 Qualified | R4, R7 | FP-RK73H2A-IPC_C | CMP-04015-088604-1 | 2

RK73H2ATTD2002F | | R6 | RESC2013X60X30LL20 T20 | CMP-2001-02185-1 | 1

RK73H2ATTD8201F | | R8 | RESC2013X60X30NL2 0T20 | CMP-2001-02517-1 | 1

RK73H2ATTED1000F | 100Ω±1%0.25WChip Resistor 0805Thick Film AEC-Q200 Qualified | R9, R10 | FP-RK73H2A-IPC_A | CMP-04015-093159-1 | 2

RCC08050000Z0EA | RCC08050000Z0EA ResThickFilm 08050 OhmConformal CoatedPadSMD AutomotiveAEC-Q200 T/R | R11 | FP-RCC0805-e3-MFG | CMP-00030-108211984-1 | 1

TL3305BF160QG | Switch | S1 | TL3305BF160QG | TL3305BF160QG | 1
ATmega328P-AU | 8-bit AVR Microcontroller, 32KB Flash, 1KBEEPROM, 2KBSRAM, 32-pin TQFP, Industrial Grade (-40°Cto85°C) | U1 | 32A_M | CMP-0095-00269-2 | 1

ECS-160-18-5PX-GM-TR | Crystal or Oscillator | Y1 | ECS160185PXGMTR | ECS-160-18-5PX-GM-TR | 1
